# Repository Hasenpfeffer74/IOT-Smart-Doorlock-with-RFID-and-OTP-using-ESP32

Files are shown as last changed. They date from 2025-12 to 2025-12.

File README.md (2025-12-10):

# IOT Smart Doorlock with RFID & OTP using ESP32
> **Lưu ý:** Đây là dự án đại học đầu tiên của chúng em, sẽ có nhiều sai sót. Rất mong nhận được sự thông cảm và góp ý của mọi người.
## Giới thiệu (VN)
Dự án cung cấp một hệ thống khóa cửa thông minh sử dụng ESP32 với ba phương thức mở khóa: thẻ RFID, mã OTP và mã PIN. Hệ thống được thiết kế đơn giản, dễ tích hợp và phù hợp cho các ứng dụng nhà trọ, văn phòng hoặc mô hình IoT học thuật.

Hệ thống gồm các thành phần chính: ESP32, RC522 RFID, Keypad 4x4, LCD I2C, relay điều khiển khóa từ, buzzer và nguồn DC–DC. ESP32 kết nối Wi-Fi để gửi OTP qua Internet.

## Tính năng
* Mở khóa bằng thẻ RFID đã đăng ký.
* Mở khóa bằng OTP được gửi qua Telegram/email/app.
* Mở khóa bằng mã PIN cố định.
* Hiển thị trạng thái trên LCD.
* Ghi log lượt mở khóa.
* Điều khiển khóa bằng relay hoặc servo.

## Phần cứng chính
* **Vi điều khiển:** ESP32 Devkit.
* **Đầu đọc thẻ:** RFID RC522.
* **Nhập liệu:** Keypad 4×4.
* **Hiển thị:** LCD 1602 I2C.
* **Cơ cấu chấp hành:** Relay 5V điều khiển khóa điện từ 12V.
* **Thông báo:** Buzzer + LED báo trạng thái.
* **Nguồn:** Ổn áp nguồn từ 12V → 5V → 3.3V.

## Cách hoạt động
1.  Người dùng chọn phương thức: RFID, OTP hoặc PIN.
2.  ESP32 xử lý thông tin, kiểm tra tính hợp lệ.
3.  Nếu xác thực thành công, relay cấp nguồn cho khóa điện từ → cửa mở.
4.  Hệ thống tự động khóa lại sau vài giây.

---

# English Version
> **Note:** This is our first university project, so there may be errors and shortcomings. We highly appreciate your understanding and feedback.
## Introduction
This project implements a simple IoT smart doorlock system using an ESP32. It supports three authentication methods: RFID card, OTP code, and PIN input. The system is designed to be lightweight, easy to integrate, and suitable for home, office, or academic IoT demonstration projects.

It uses common hardware modules such as ESP32, RC522, keypad, LCD display, and a relay to drive a 12V solenoid lock.

## Features
* Unlock with registered RFID card.
* Unlock with OTP sent via Telegram/email/app.
* Unlock with a predefined PIN code.
* LCD display for status messages.
* Event logging for all unlock attempts.
* Relay/servo to control the lock mechanism.

## Hardware Overview
* **Controller:** ESP32 Devkit board.
* **Reader:** RC522 RFID reader.
* **Input:** 4×4 keypad.
* **Display:** LCD 1602 I2C.
* **Actuator:** 5V relay controlling 12V solenoid lock.
* **Notification:** Buzzer and indicator LED.
* **Power:** 12V → 5V/3.3V power modules.

## How It Works
1.  User chooses RFID, OTP, or PIN authentication.
2.  ESP32 verifies the credentials.
3.  If valid, relay activates and unlocks the door.
4.  The system automatically locks again after a short delay.

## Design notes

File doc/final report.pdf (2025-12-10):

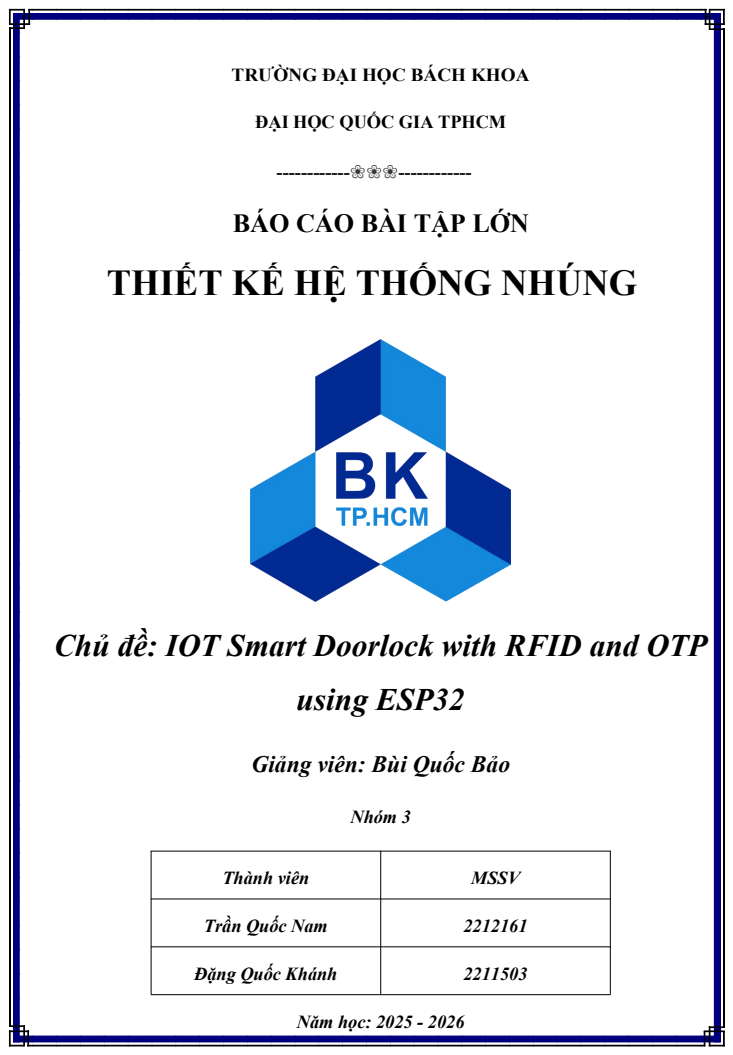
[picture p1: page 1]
using ESP32; Nhóm 3; Năm học: 2025 - 2026

TRƯỜNG ĐẠI HỌC BÁCH KHOA
ĐẠI HỌC QUỐC GIA TPHCM
------------❀❀❀------------ BÁO CÁO BÀI TẬP LỚN

THIẾT KẾ HỆ THỐNG NHÚNG

Chủ đề: IOT Smart Doorlock with RFID and OTP

Giảng viên: Bùi Quốc Bảo

Thành viên | MSSV

Trần Quốc Nam | 2212161

Đặng Quốc Khánh | 2211503

i

### MỤC LỤC

Error! The style is not specified. | 1

### CHƯƠNG 1: TỔNG QUAN

### 1.1. Vấn đề (Problem)

Các loại khóa cơ truyền thống bộc lộ nhiều hạn chế về an ninh (dễ bị cắt phá, sao chép chìa) và bất tiện khi sử dụng (quên chìa, mất chìa). Việc quản lý ra vào tại các khu vực cần bảo mật hoặc nhà trọ, văn phòng gặp nhiều khó khăn. 1.2. Ý nghĩa (Significance)

Đồ án thiết kế hệ thống khóa cửa điện tử sử dụng công nghệ thẻ từ RFID và mật khẩu số giúp nâng cao tính bảo mật, loại bỏ sự phụ thuộc vào chìa khóa cơ, đồng thời tạo tiền đề cho việc tích hợp quản lý từ xa qua Internet (IoT). 1.3. Ứng dụng (Application)

Mặc dù đây là một mô hình đồ án môn học, nhưng hệ thống khóa cửa thông minh (Smart Door Lock) được thiết kế với độ hoàn thiện cao, có tính ứng dụng thực tiễn rộng rãi trong đời sống và công nghiệp: - Hệ thống an ninh nhà ở (Smart Home): Thay thế ổ khóa cơ truyền thống tại các

căn hộ chung cư, nhà phố thông minh, giúp gia chủ không cần mang theo chùm chìa khóa cồng kềnh. - Kiểm soát ra vào văn phòng (Access Control): Ứng dụng tại các công ty, phòng

họp hoặc khu vực hạn chế (như phòng Server, kho tài liệu) để chỉ cho phép nhân viên có thẻ từ hoặc mật khẩu được cấp quyền mới được phép ra vào. - Quản lý khu nhà trọ, khách sạn (Hospitality): Giúp chủ nhà trọ quản lý người thuê

dễ dàng. Khi khách trả phòng, chỉ cần xóa mã thẻ/mật khẩu trên hệ thống mà không cần tốn chi phí thay toàn bộ ổ khóa như khóa cơ. - Tủ đồ cá nhân (Smart Locker): Ứng dụng cho hệ thống tủ gửi đồ tại siêu thị, phòng Gym, hồ bơi, tăng tính an toàn và tiện lợi cho khách hàng.

- Giáo dục và Nghiên cứu: Sản phẩm là mô hình trực quan để sinh viên nghiên cứu về lập trình hệ thống nhúng, các chuẩn giao tiếp (SPI, I2C, GPIO) và kỹ thuật điều khiển thiết bị ngoại vi trên nền tảng ESP32. 1.4. Mục tiêu (Objective)

Xây dựng hoàn thiện hệ thống khóa cửa thông minh với các chức năng: - Mở khóa bằng thẻ từ RFID. - Mở khóa bằng mật khẩu (Keypad). - Hiển thị trạng thái trên màn hình LCD. - Hệ thống hoạt động ổn định với nguồn 12V, điều khiển chốt cửa điện từ

(Solenoid Lock).

### CHƯƠNG 2: TỔNG QUAN HỆ THỐNG

### 2.1. Requirements

### 2.1.1. Functional Requirement

ID | Requirement Description
FR1 | Mở khóa bằng RFID
FR2 | Mở khóa bằng OTP (One-Time Password)
FR3 | Mở khóa bằng PIN
FR4 | Quản lý mở khóa

FR1 – Hệ thống cho phép người dùng mở khóa bằng thẻ RFID

- FR1.1. Hệ thống phải cho phép mở khóa bằng thẻ RFID hợp lệ. - FR1.2. Hệ thống phải lưu trữ và quản lý danh sách thẻ RFID được phép sử

dụng. - FR1.3. Khi quét thẻ không hợp lệ, hệ thống phải từ chối và hiển thị cảnh

báo. FR2 – Hệ thống cho phép người dùng mở khóa bằng OTP (One-Time

Password)

- FR2.1. Hệ thống phải sinh OTP ngẫu nhiên và có thời hạn sử dụng (< 60 giây). - FR2.2. OTP phải được gửi đến người dùng qua ứng dụng di

động/Telegram/email tùy cấu hình. - FR2.3. Hệ thống chỉ mở khóa khi OTP nhập vào khớp và còn hiệu lực.

FR3 – Hệ thống cho phép người dùng mở khóa bằng PIN

- FR3.1. Hệ thống phải cho phép người dùng nhập PIN cố định để mở khóa. - FR3.2. Người dùng có thể thay đổi PIN thông qua giao diện quản lý. - FR3.3. Khi nhập sai PIN nhiều lần liên tiếp, hệ thống phải khóa tạm thời và

cảnh báo. FR4 – Quản lý mở khóa

- FR4.1. Hệ thống phải điều khiển khóa điện tử (servo/relay) để mở hoặc đóng. - FR4.2. Hệ thống phải ghi lại log sự kiện. - FR4.3. Hệ thống phải cho phép reset và cập nhật firmware qua OTA (Over- The-Air). 2.1.2. Non-Functional Requirements
ID | Requirement Description
NFR1 | Thời gian phản hồi khi quét RFID, nhập OTP hoặc PIN không vượt quá 2
| giây. NFR2 Hệ thống phải hoạt động liên tục 24/7 với tỉ lệ lỗi < 1%. NFR3 Dữ liệu OTP/PIN phải được mã hóa khi truyền, và giao tiếp phải sử dụng
| HTTPS/TLS. NFR4 Hệ thống phải tiêu thụ điện năng thấp, có thể dùng pin/UPS trong trường
| hợp mất điện. NFR5 Hệ thống phải dễ mở rộng để tích hợp thêm cảm biến (camera, vân tay, cảm biến cửa…).

NFR1 – Thời gian phản hồi - NRF1.1: RFID/OTP/PIN phải được xử lý trong ≤ 2 giây. - NRF1.2: Nếu vượt ngưỡng thì hệ thống phải ghi log sự kiện lỗi. NFR2 – Độ tin cậy hệ thống

- NFR2.1: Hệ thống phải hoạt động liên tục 24/7 với uptime ≥ 99%. - NFR2.2: Có cơ chế tự khởi động lại khi treo. - NFR2.3: Khi mất mạng, RFID/PIN vẫn hoạt động offline. - NFR2.4: Tuổi thọ phần cứng tối thiểu 2 năm. NFR3 – Bảo mật dữ liệu
- NFR3.1: OTP/PIN phải được mã hóa (AES-128 trở lên). - NFR3.2: Giao tiếp sử dụng HTTPS/TLS. - NFR3.3: Không được lưu OTP dưới dạng plaintext. NFR4 – Tiêu thụ năng lượng
- NFR4.1: Có pin/UPS dự phòng ≥ 4 giờ trong trường hợp mất điện. - NFR4.2: Cảnh báo pin yếu hiển thị trên App. NFR5 – Khả năng mở rộng
- NFR5.1: Hỗ trợ tích hợp thêm cảm biến (camera, vân tay, cảm biến cửa). - NFR5.2: Cho phép giao tiếp mở rộng qua UART/I2C/SPI. - NFR5.3: Có thể quản lý cảm biến bổ sung qua App/Web. 2.1. Use Case Modelling

Hệ thống được thiết kế với 3 kịch bản sử dụng chính: Mở khóa bằng mật khẩu, Mở khóa bằng thẻ từ và Xử lý khi nhập sai (Báo động). - UC – 01: Mở khóa bằng Mật khẩu (Password Unlock)

- Mô tả: Người dùng nhập mật khẩu đã cài đặt trước thông qua bàn phím (Keypad) để mở khóa cửa. • Các bước thực hiện:

- Hệ thống ở trạng thái chờ, LCD hiển thị thông báo "Moi nhap mat khau". o Người dùng nhập các ký tự số trên Keypad 4x4. o LCD hiển thị ký tự * thay cho số thực để bảo mật. o Người dùng nhấn phím # để xác nhận. o Hệ thống kiểm tra mật khẩu. Nếu đúng:
- Buzzer kêu 1 tiếng "bíp" ngắn. o Relay đóng mạch, Solenoid rút chốt mở cửa. o LCD hiển thị "Welcome Home". o Sau 5 giây, Solenoid tự động bung chốt để khóa lại. • Yêu cầu: Hệ thống đã được cấp nguồn và mật khẩu đã được lưu trong bộ

nhớ. - UC – 02: Mở khóa bằng Thẻ RFID (RFID Unlock)

- Mô tả: Người dùng sử dụng thẻ từ hoặc móc khóa RFID đã đăng ký để chạm vào đầu đọc mở cửa nhanh chóng. • Các bước thực hiện:
- Hệ thống ở trạng thái chờ, module RFID liên tục phát sóng dò tìm thẻ. o Người dùng đưa thẻ vào phạm vi quét (2-5cm). o Đầu đọc RC522 đọc mã UID của thẻ và gửi về ESP32. o Hệ thống so sánh UID với danh sách hợp lệ. Nếu khớp:
- Buzzer kêu 1 tiếng "bíp". o Relay kích hoạt Solenoid mở cửa. o LCD hiển thị "Card Accepted". o Cửa tự động khóa lại sau 5 giây. • Yêu cầu: Thẻ RFID phải là thẻ hoạt động ở tần số 13.56MHz và đã được

nạp UID vào Code. - UC – 03: Xử lý truy cập trái phép (Access Denied)

- Mô tả: Hệ thống phản hồi khi người dùng nhập sai mật khẩu hoặc sử dụng thẻ từ không hợp lệ. • Các bước thực hiện:
- Người dùng nhập sai mật khẩu và nhấn #, hoặc quẹt thẻ chưa đăng ký. o Hệ thống kiểm tra thấy dữ liệu không trùng khớp. o Buzzer phát ra âm thanh cảnh báo (3 tiếng "bíp" dài hoặc kêu liên tục

1s). o LCD hiển thị thông báo lỗi "Wrong Password" hoặc "Invalid Card". o Relay không hoạt động, cửa vẫn ở trạng thái khóa. o Hệ thống quay lại trạng thái chờ sau 2 giây. • Yêu cầu: Hệ thống hoạt động bình thường. 2.2. System Architecture

Kiến trúc hệ thống bao gồm các khối chính là Khối nguồn, Khối hiển thị, Khối vi điều khiển, Khối di chuyển, Khối cảm biến và Khối nạp code. Trong đó: - Khối nguồn: Nguồn 12V, mạch ổn áp tạo nguồn 5V và mạch ổn áp tạo nguồn 3.3V. - Khối hiển thị: Hiển thị thông qua LCD và thông báo bằng led và buzzer. - Khối vi điều khiển: Thực hiện điều khiển các khối còn lại. - Khối chấp hành : Nhận tín hiệu kích từ vi điều khiển để cấp nguồn cho khóa. - Khối nhập liệu: Dùng để nhập dữ liệu vào. - Khối nạp code: Dùng để nạp code vào khối vi điều khiển.

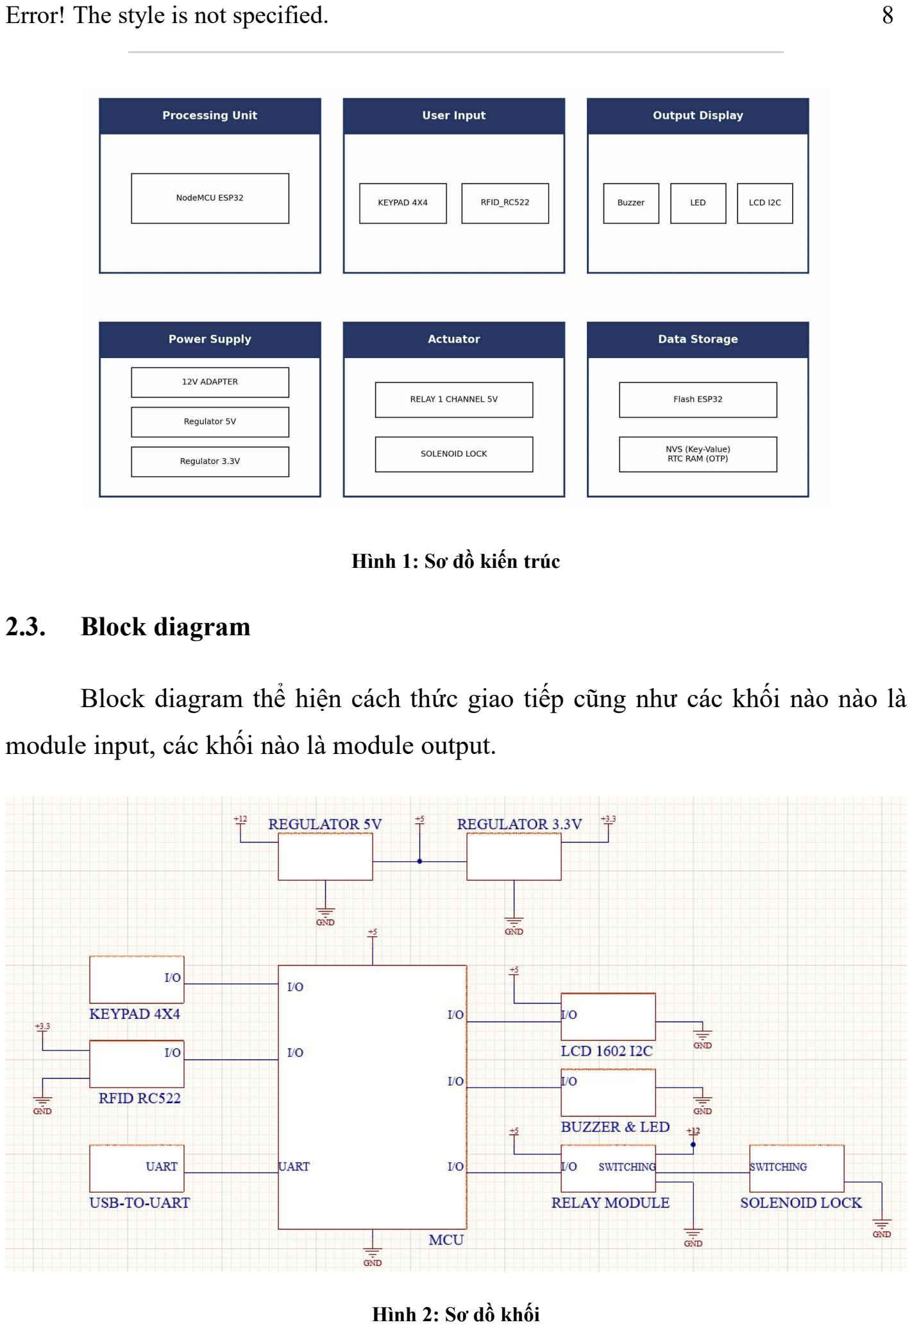
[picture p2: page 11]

Hình 1: Sơ đồ kiến trúc

### 2.3. Block diagram

Block diagram thể hiện cách thức giao tiếp cũng như các khối nào nào là module input, các khối nào là module output.

Hình 2: Sơ dồ khối

### CHƯƠNG 3 THIẾT KẾ PHẦN CỨNG

### 3.1. Khối nguồn

Hệ thống sử dụng mô hình hạ áp tầng (Cascade) để đảm bảo ổn định nhiệt và hiệu suất.- Đầu vào: 12V DC (cần thiết để Solenoid hoạt động mạnh). - Tầng 1 (12V -> 5V): Sử dụng IC L7805 để cấp nguồn cho Relay, LCD, Buzzer. Có Diode bảo vệ chống ngược cực và tụ lọc nhiễu. - Tầng 2 (5V -> 3.3V): Sử dụng IC AMS1117-3.3 để cấp nguồn cho ESP32

và module RFID (vì ESP32 và RFID hoạt động ở 3.3V, nếu cấp 5V sẽ cháy).

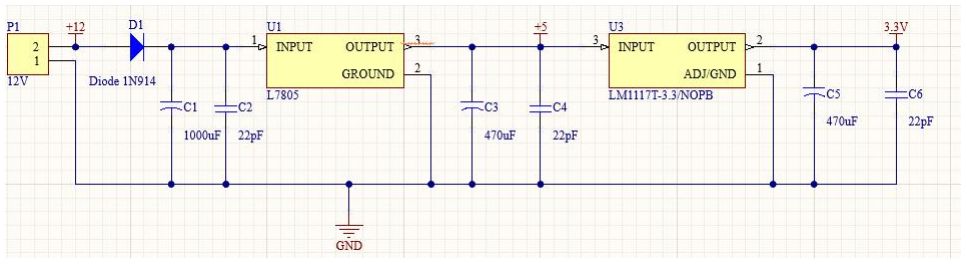
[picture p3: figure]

Hình 3: Khối nguồn

### 3.2. Khối hiển thị - LCD 1602: Sử dụng giao tiếp I2C (chân SDA, SCL) giúp tiết kiệm chân

GPIO của vi điều khiển. - Buzzer: Sử dụng Transistor NPN (C1815/2N2222) để khuếch đại dòng điện

từ chân GPIO, đảm bảo còi kêu to và bảo vệ vi điều khiển. - Led: Sử dụng LED đơn (màu Xanh) kết nối nối tiếp với điện trở hạn dòng

vào chân GPIO. Cung cấp phản hồi thị giác tức thời cho người dùng (Sáng khi mở khóa thành công, tắt hoặc nhấp nháy khi khóa/báo lỗi) hỗ trợ cho màn hình LCD và còi Buzzer.

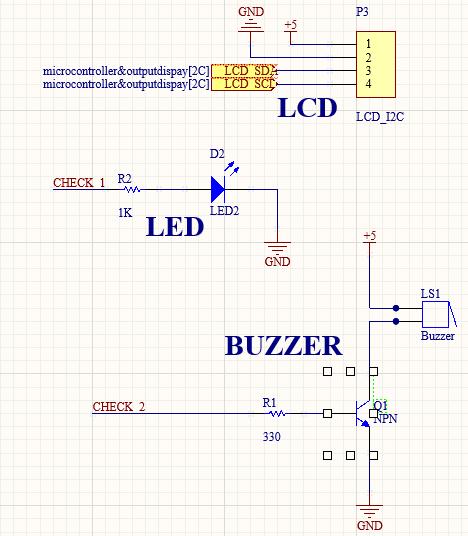
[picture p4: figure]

Hình 4: Khối hiển thị

### 3.3. Khối vi điều khiển

MCU: NodeMCU ESP32 được lựa chọn nhờ tốc độ xử lý cao (Dual-core 240MHz), bộ nhớ lớn và tích hợp sẵn Wi-Fi/Bluetooth cho các tính năng IoT mở rộng.

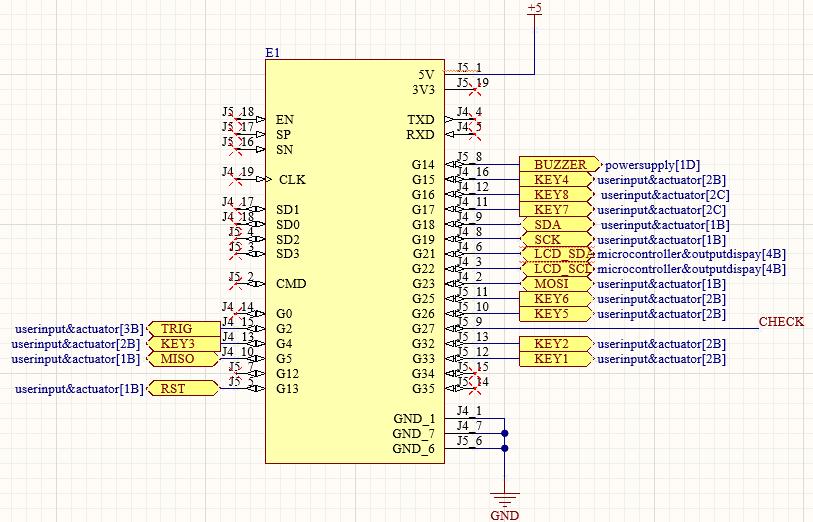
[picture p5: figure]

Hình 5: Khối vi điều khiển

### 3.4. Khối chấp hành

Đây là phần quan trọng nhất để đóng/mở cửa. - Relay 5V: Đóng vai trò cách ly giữa vi điều khiển (3.3V) và khóa từ (12V). - Solenoid Lock: Sử dụng nguồn 12V.

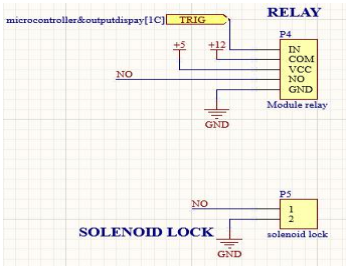
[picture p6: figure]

Hình 6: Khối chấp hành

### 3.5. Khối nhập liệu

- RFID RC522: Giao tiếp qua chuẩn SPI (MOSI, MISO, SCK, SS) cho tốc độ đọc thẻ nhanh. - Keypad 4x4: Kết nối 8 chân GPIO, sử dụng thư viện Keypad.h để quét ma

trận phím.

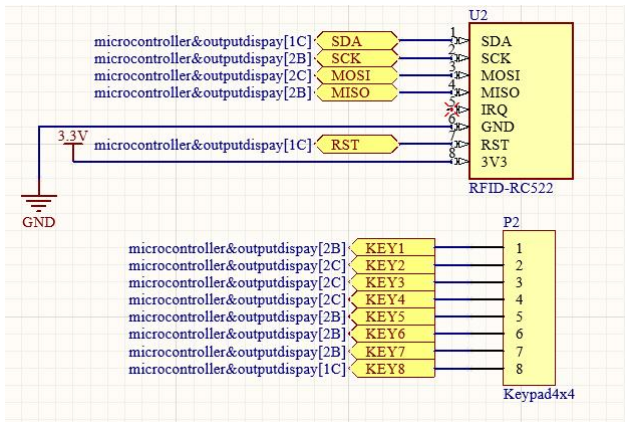
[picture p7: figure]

Hình 7: Khối nhập liệu

### CHƯƠNG 4: THIẾT KẾ PHẦN MỀM

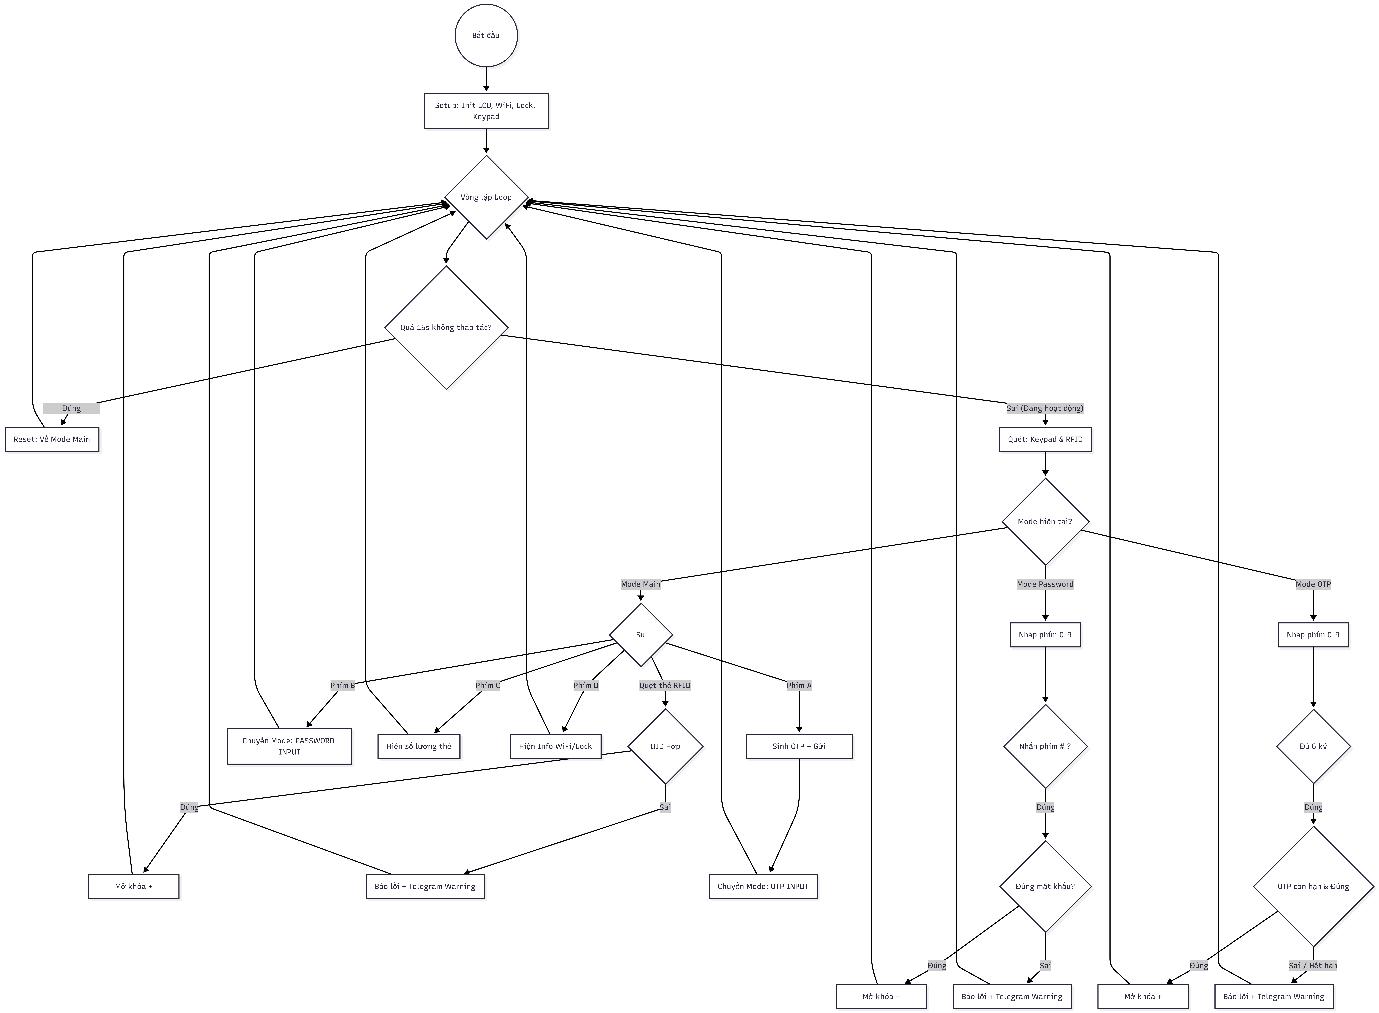
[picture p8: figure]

Hình 8: Flowchart của hệ thống

Dựa trên flowchart, hệ thống sẽ hoạt động theo luồng sau: - Trạng thái SETUP (Khởi tạo): Khi bắt đầu (Start), hệ thống thực hiện khởi tạo các

thành phần phần cứng bao gồm: màn hình LCD, kết nối WiFi, module khóa (Lock) và bàn phím (Keypad). Sau khi hoàn tất, hệ thống chuyển sang vòng lặp chính (Loop). - Trạng thái CHECK TIMEOUT (Kiểm tra thời gian chờ): Trong vòng lặp, hệ

thống liên tục kiểm tra thời gian không hoạt động. Nếu phát hiện quá 15 giây người dùng không thao tác, hệ thống thực hiện Reset: đưa giao diện về màn hình chính (Mode Main) và xóa các bộ đệm nhập liệu để bảo mật. Nếu hệ thống đang được thao tác (thời gian < 15s), hệ thống chuyển sang trạng thái quét tín hiệu đầu vào (Scan Inputs). - Trạng thái MODE MAIN (Màn hình chính): Hệ thống quét tín hiệu từ Keypad và

RFID. Tại đây xử lý các sự kiện:
- Quẹt thẻ RFID: Hệ thống kiểm tra UID. Nếu Đúng (hợp lệ), thực hiện mở khóa và gửi thông báo Telegram. Nếu Sai, báo lỗi truy cập và gửi cảnh báo Telegram. o Phím A: Hệ thống sinh mã OTP, gửi mã qua Telegram, sau đó chuyển trạng

thái sang Mode OTP. o Phím B: Hệ thống chuyển trạng thái sang Mode Password. o Phím C: LCD hiển thị số lượng thẻ RFID hợp lệ đã lưu. o Phím D: LCD hiển thị thông tin trạng thái WiFi và trạng thái Khóa. - Trạng thái MODE PASSWORD (Nhập mật khẩu): Người dùng nhập các phím số

(0-9). Khi nhấn phím #, hệ thống kiểm tra mật khẩu:
- Đúng: Thực hiện mở khóa và gửi thông báo Telegram. o Sai: Hệ thống hiển thị lỗi, báo động và gửi cảnh báo Telegram. - Trạng thái MODE OTP (Nhập mã xác thực): Người dùng nhập các phím số. Khi

bộ đệm đủ 6 ký tự, hệ thống tự động kiểm tra tính hợp lệ (mã đúng và còn thời hạn):
- Đúng & Còn hạn: Thực hiện mở khóa và gửi thông báo Telegram. o Sai hoặc Hết hạn: Hệ thống từ chối truy cập, báo lỗi tương ứng và gửi cảnh

báo Telegram.

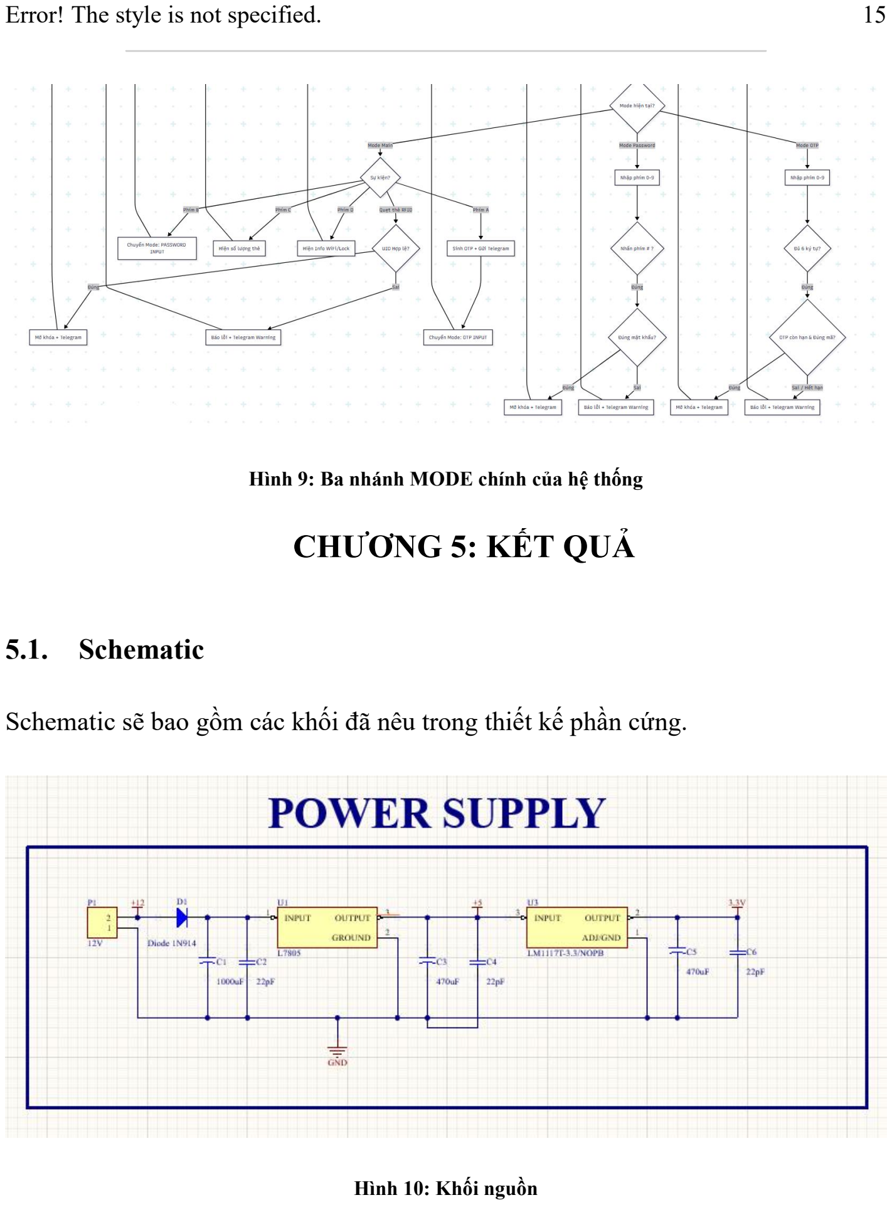
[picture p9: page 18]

Hình 9: Ba nhánh MODE chính của hệ thống

### CHƯƠNG 5: KẾT QUẢ

### 5.1. Schematic

Schematic sẽ bao gồm các khối đã nêu trong thiết kế phần cứng.

Hình 10: Khối nguồn

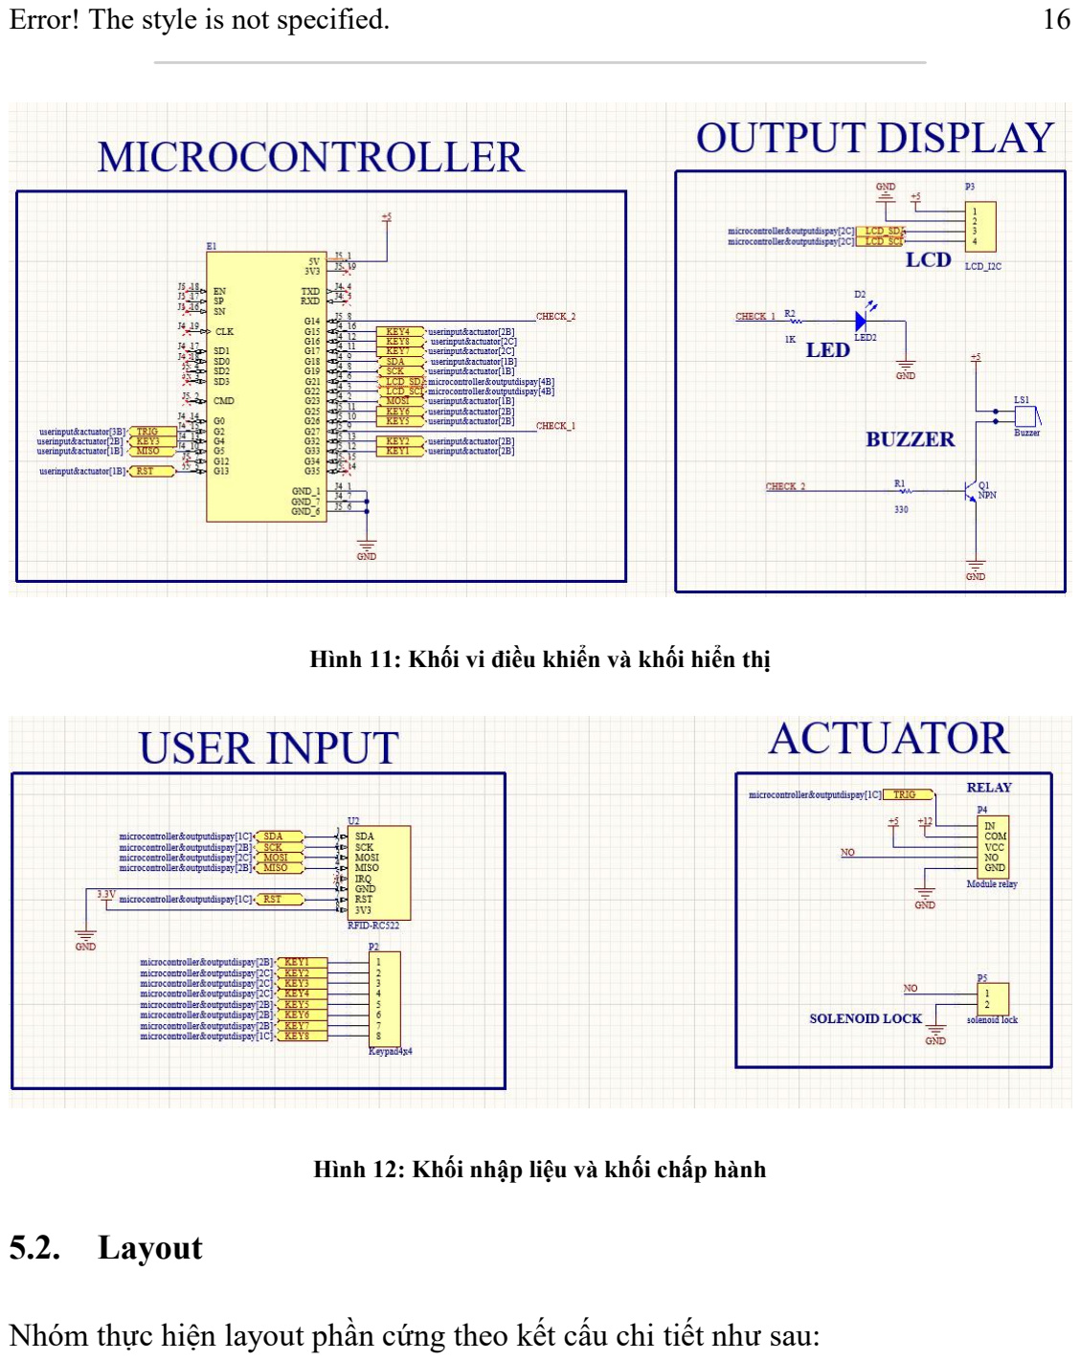
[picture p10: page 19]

Hình 11: Khối vi điều khiển và khối hiển thị

Hình 12: Khối nhập liệu và khối chấp hành

### 5.2. Layout

Nhóm thực hiện layout phần cứng theo kết cấu chi tiết như sau:

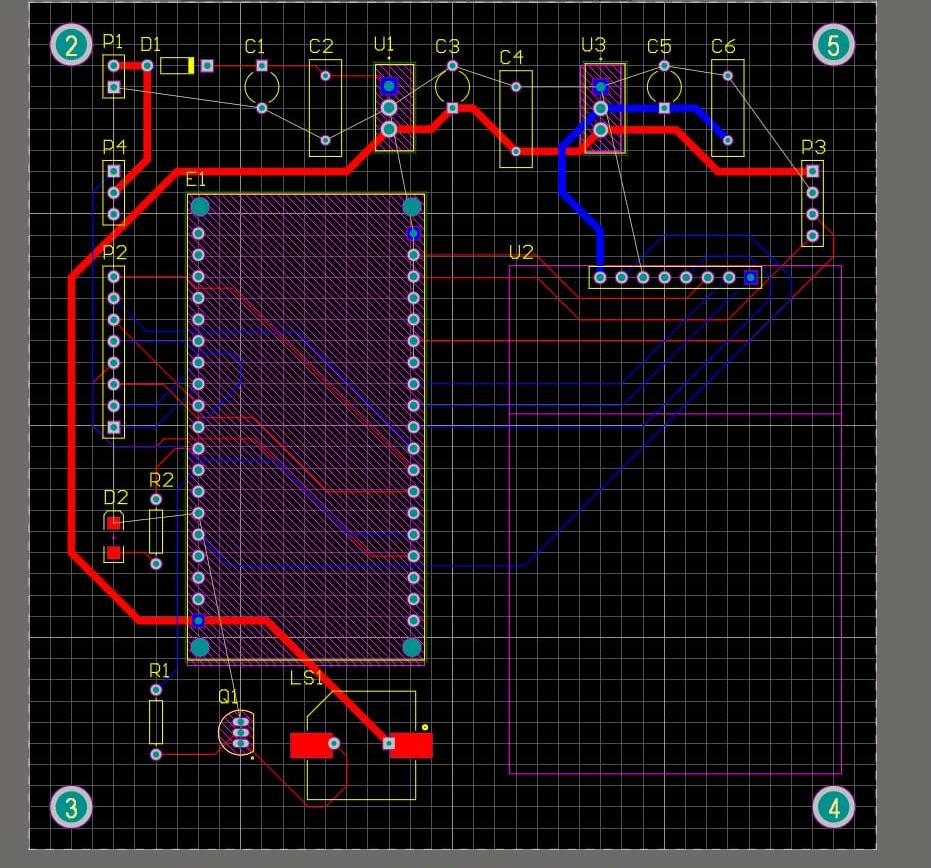
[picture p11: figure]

Hình 13: Layout của hệ thống

### 5.3. Kết quả dự án

Sau khi thiết kế và xây dựng, kết quả dự án như sau:

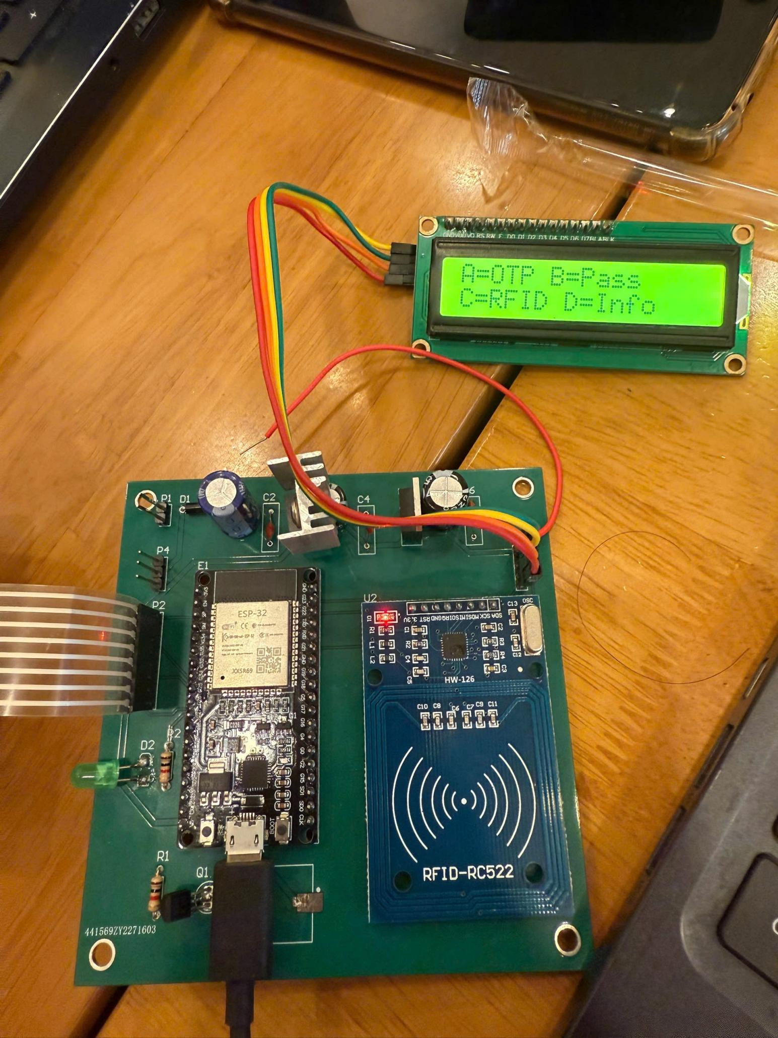
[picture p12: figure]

Hình 14: MODE của hệ thống

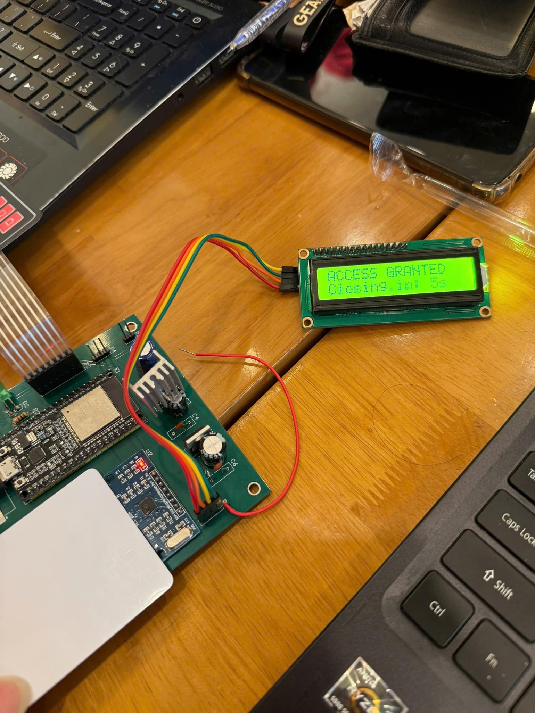
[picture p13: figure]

Hình 15: Màn hình LCD thể hiện khóa được mở trong 5s

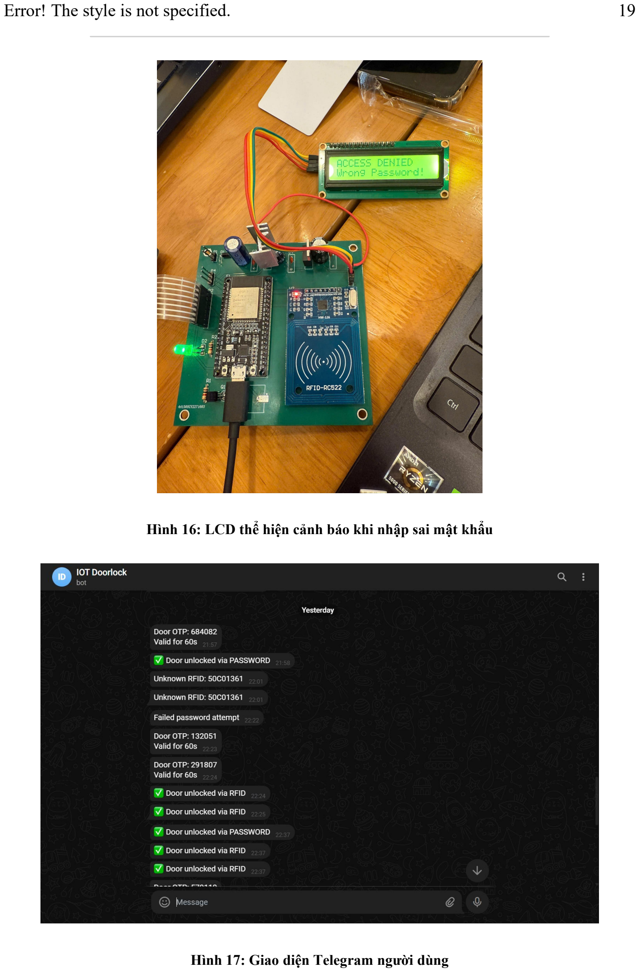
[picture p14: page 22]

Hình 16: LCD thể hiện cảnh báo khi nhập sai mật khẩu

Hình 17: Giao diện Telegram người dùng

### CHƯƠNG 6 TỔNG KẾT

Nhóm đã thiết kế và thi công thành công hệ thống khóa cửa thông minh tích hợp công nghệ IoT, hoàn thành mục tiêu xây dựng một thiết bị hoạt động ổn định trên nền tảng vi điều khiển ESP32. Hệ thống đã khắc phục được những hạn chế về an ninh và sự bất tiện của các loại khóa cơ truyền thống thông qua việc tích hợp đa dạng phương thức xác thực và khả năng quản lý từ xa qua Internet, tạo tiền đề cho các ứng dụng Smart Home hiện đại. Cụ thể, hệ thống đáp ứng tốt các yêu cầu chức năng và phi chức năng đã đề ra: - Khả năng bảo mật và vận hành đa dạng: Hệ thống thực hiện mở khóa chính

xác và nhanh chóng thông qua 3 phương thức: thẻ từ RFID, mật khẩu số (Keypad) và mã xác thực một lần (OTP), đảm bảo tính an toàn cao thay thế cho chìa khóa vật lý. - Giao diện trực quan và giám sát IoT: Trạng thái cửa được hiển thị thời gian

thực trên màn hình LCD và đồng bộ hóa thông báo về ứng dụng Telegram trên điện thoại, giúp người dùng dễ dàng theo dõi lịch sử ra vào và nhận cảnh báo truy cập trái phép tức thời. - Tính năng tự động hóa: Hệ thống hoạt động theo quy trình khép kín với cơ

chế tự động đóng chốt khóa sau 5 giây mở và tự động kích hoạt báo động (Buzzer) khi nhập sai dữ liệu nhiều lần, đảm bảo an ninh 24/7.

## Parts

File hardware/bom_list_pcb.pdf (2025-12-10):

Comment | Description | Designator | Footprint | LibRef | Quantity
Cap2 | Capacitor | C1, C3, C5 | CAPR5-4X5 | Cap2 | 3
Cap | Capacitor | C2, C4, C6 | RAD-0.3 | Cap | 3
Diode1N914 | HighConductance Fast Diode | D1 | DO-35 | Diode1N914 | 1
LED2 | Typical RED, GREEN, YELLOW, AMBERGaAs LED | D2 | 3.2X1.6X1.1 | LED2 | 1
| NodeMCUis anopen source loTplatform. ESP32is aseriesof lowcost, low powersystem-on-chip (SoC)microcontrollers with integratedWi-Fi anddual-mode Bluetooth. | E1 | MODULE_ESP32_NOD EMCU | ESP32_NODEMCU | 1
Buzzer | Magnetic Transducer Buzzer | LS1 | ABSM-1574 | Buzzer | 1
12V | Header, 2-Pin | P1 | HDR1X2 | Header 2 | 1
Keypad4x4 | Header, 8-Pin | P2 | HDR1X8 | Header 8 | 1
LCD_I2C | Header, 4-Pin | P3 | HDR1X4 | Header 4 | 1
Header 3 | Header, 3-Pin | P4 | HDR1X3 | Header 3 | 1
NPN | NPNBipolar Transistor | Q1 | TO-226-AA | NPN | 1
Res1 | Resistor | R1, R2 | AXIAL-0.3 | Res1 | 2
L7805 | StandardRegulator Pos5V1.5A3-Pin(3+Tab)TO-220FP Tube | U1 | TO255P1020X450X20 00-3 | L7805 | 1
RFID-RC522 | Development kit inan integrated reader/writer IC MFRC522for contactless communicationat 13.56MHz. | U2 | RFID-RC522 | RFID-RC522 | 1
LM1117T-3.3/NOPB | 800-mA15-Vlinear voltageregulator | U3 | TO254P1054X470X19 55-3 | LM1117T-3.3/NOPB | 1

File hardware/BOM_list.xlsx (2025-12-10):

STT | Tên linh kiện | Số lượng | Đơn giá | Link
1 | Kit phát triển Wifi BLE SoC ESP32 S3 WeAct ESP32-S3-B N16R8 | 1 | 190000 | https://hshop.vn/kit-rf-thu-phat-wifi-ble-esp32-nodemcu-32s-ch340-ai-thinker
2 | Bàn phím ma trận mềm 4x4 keypad | 1 | 12000 | https://hshop.vn/ban-phim-ma-tran-mem-4x4
3 | Solenoid Lock | 1 | 27000 | https://hshop.vn/dong-co-rc-servo-9g-360
4 | Mạch RFID NFC 13.56MHz RC522 | 1 | 28000 | https://hshop.vn/mach-rfid-rc522-nfc-13-56mhz
5 | Mạch còi buzzer | 1 | 10000 | https://hshop.vn/mach-buzzer-5v
6 | Mạch hiển thị MKE-M07 LCD1602 I2C module | 1 | 95000 | https://hshop.vn/mach-hien-thi-mkl-m07-lcd1602-i2c-module
7 | LM7805 Mạch Ổn Áp 5V 1.2A | 1 | 7000 | https://www.thegioiic.com/lm7805-mach-on-ap-5v-1-2a
8 | LD1117V33 IC Ổn Áp 3.3V 800mA | 1 | 6000 | https://www.thegioiic.com/ld1117v33-ic-on-ap-3-3v-800ma
9 | Module Relay 1 Kênh 5V-220VAC10A | 1 | 30000 | https://dientu360.com/module-relay-1-kenh-5v-220vac10a-cach-ly-quang
10 | Pin Sạc 18650 Li-Ion Rechargeable Battery 3.7V 2500mAh 10C | 3 | 120000 | https://hshop.vn/pin-sac-18650-li-ion-rechargeable-battery-3-7v-2500mah-10c
111 | Tụ 470uF, 22pF, trở 1K
 |  |  | 525000

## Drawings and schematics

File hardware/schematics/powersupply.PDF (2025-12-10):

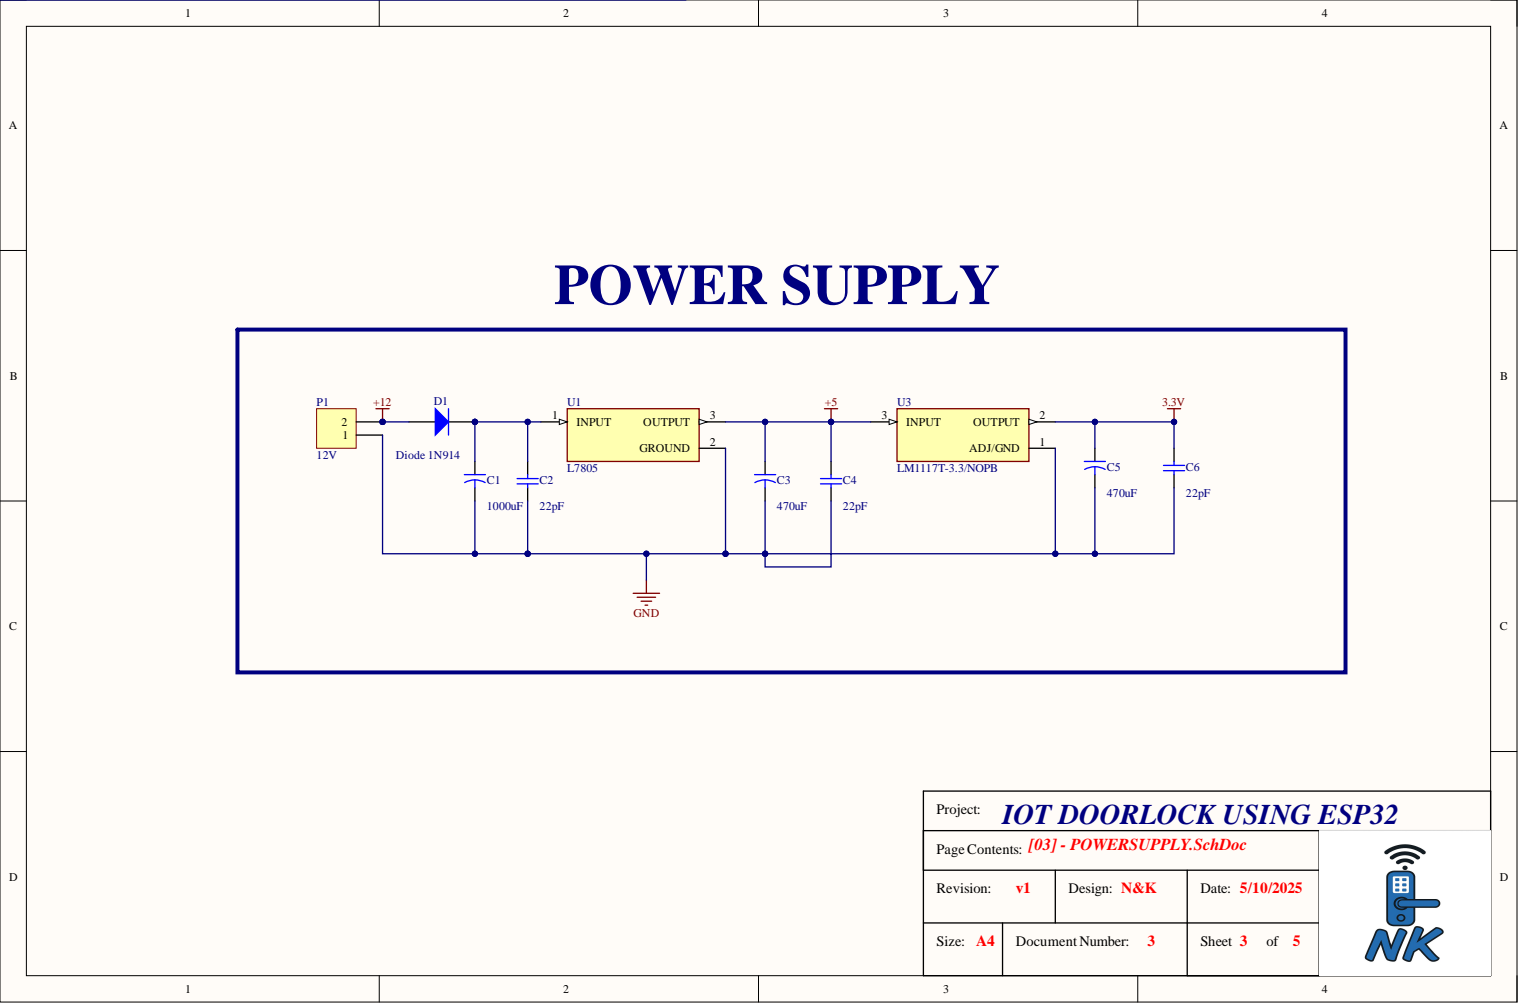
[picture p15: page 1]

[03] - POWERSUPPL Y.SchDoc P a g eCo nte n t s :

v 1 Re visi o n : | N&K Desi g n : | 5/1 0/2 0 2 5 Da te :

Siz e : A4 | Do c ume nt Nu mb e r : 3 | S h e e t 3 o f 5

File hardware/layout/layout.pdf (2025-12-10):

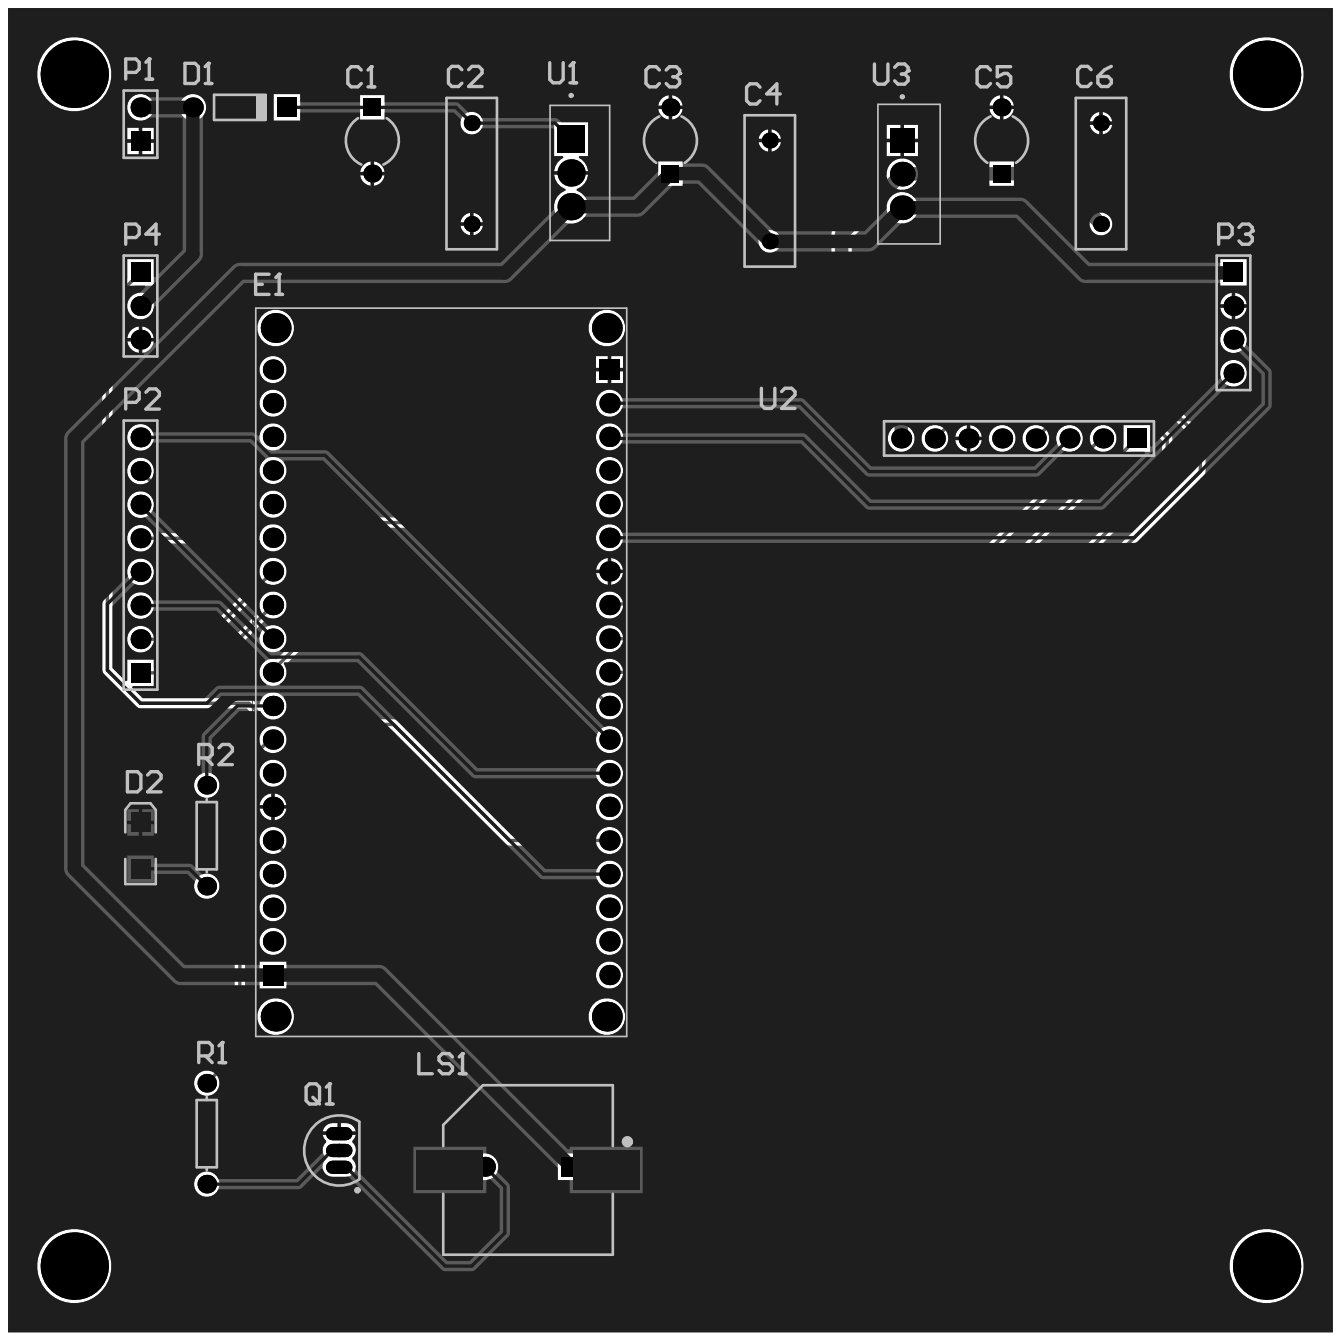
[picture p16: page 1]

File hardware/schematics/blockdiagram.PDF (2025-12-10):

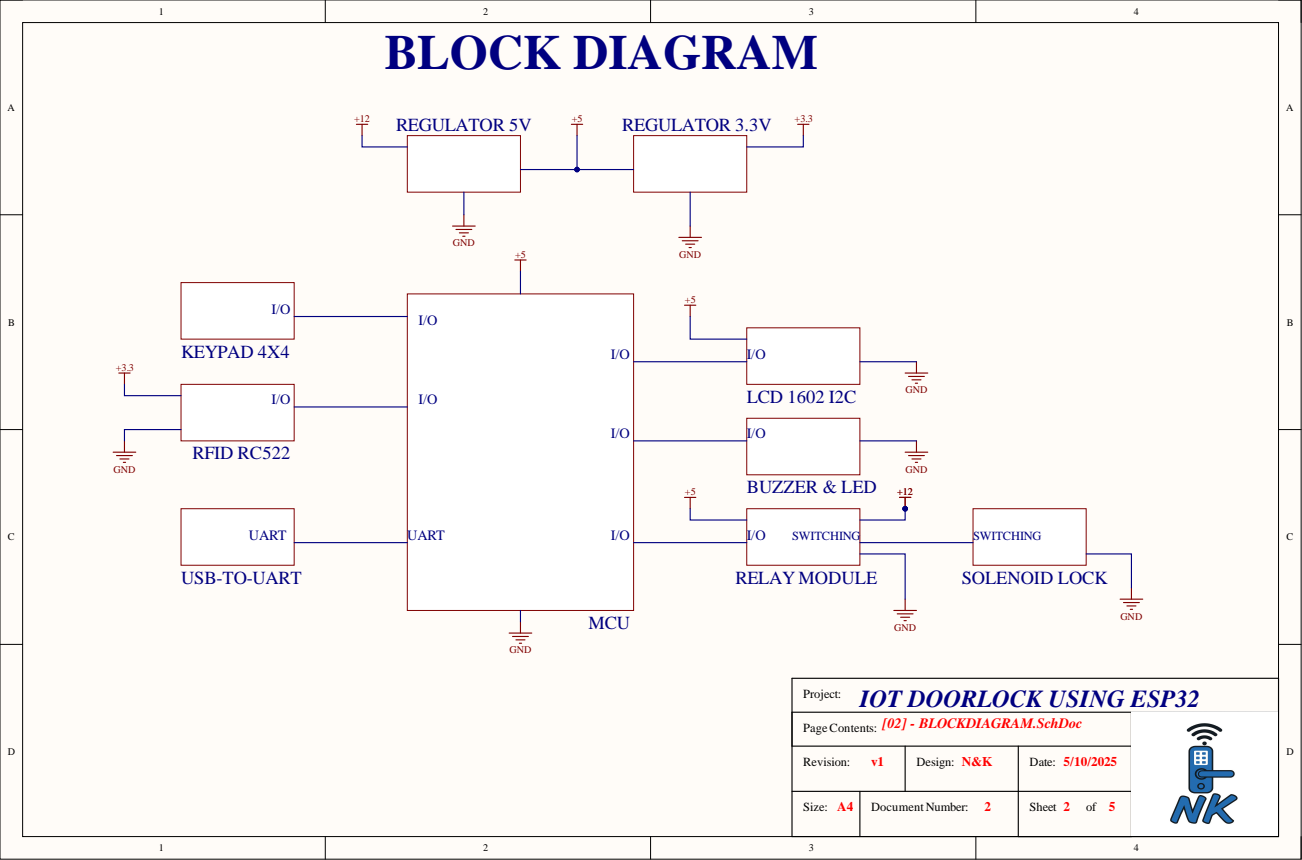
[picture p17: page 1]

[02] - BLOCKDIAGRAM.SchDoc PageContents:

v1 Revision: | N&K Design: | 5/10/2025 Date:

Size: A4 | Document Number: 2 | Sheet 2 of 5

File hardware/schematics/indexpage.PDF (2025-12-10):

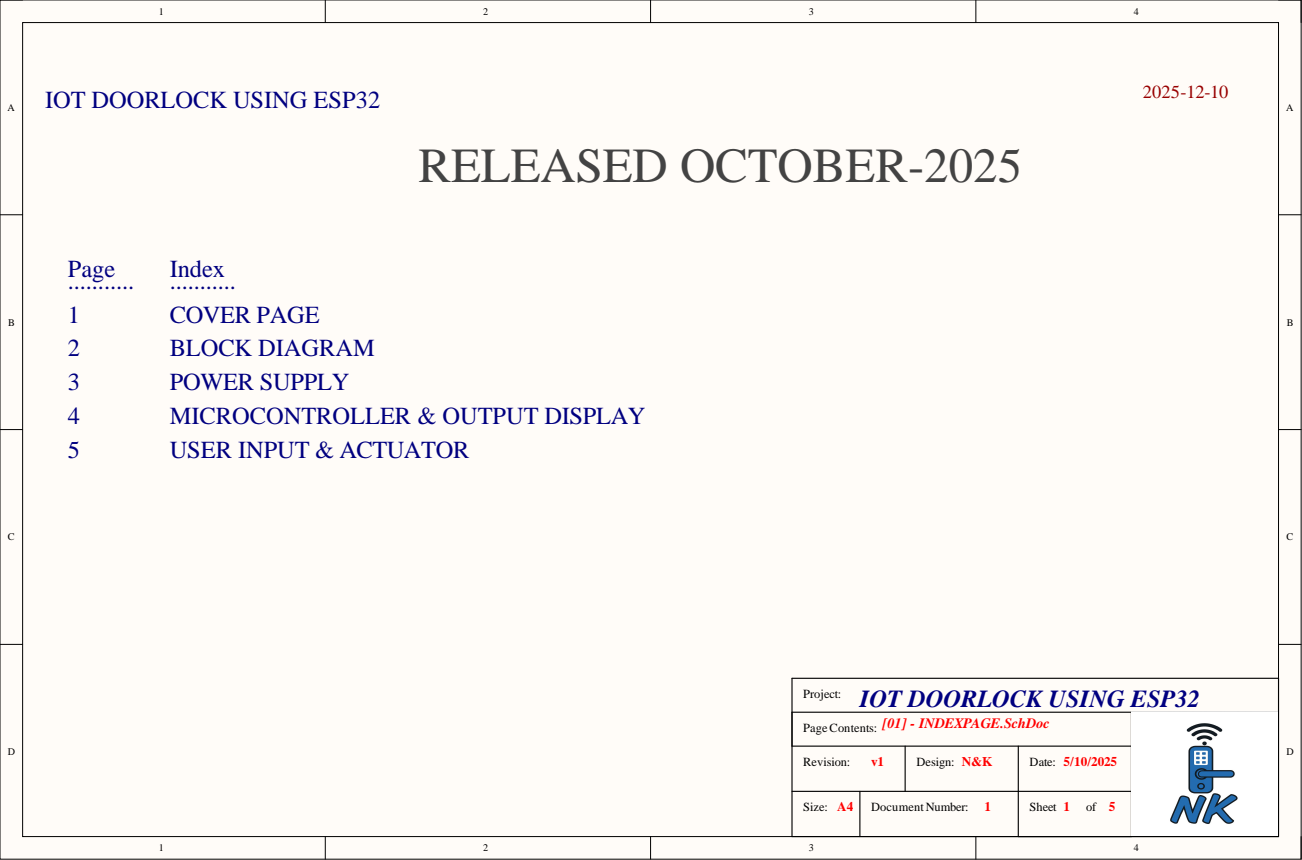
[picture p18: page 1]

[01] - INDEXPAGE.SchDoc PageContents:

v1 Revision: | N&K Design: | 5/10/2025 Date:

Size: A4 | Document Number: 1 | Sheet 1 of 5


[02] - BLOCKDIAGRAM.SchDoc PageContents:

v1 Revision: | N&K Design: | 5/10/2025 Date:

Size: A4 | Document Number: 2 | Sheet 2 of 5


[03] - POWERSUPPL Y.SchDoc P a g eCo nte n t s :

v 1 Re visi o n : | N&K Desi g n : | 5/1 0/2 0 2 5 Da te :

Siz e : A4 | Do c ume nt Nu mb r 3 | S h t 3 o f 5

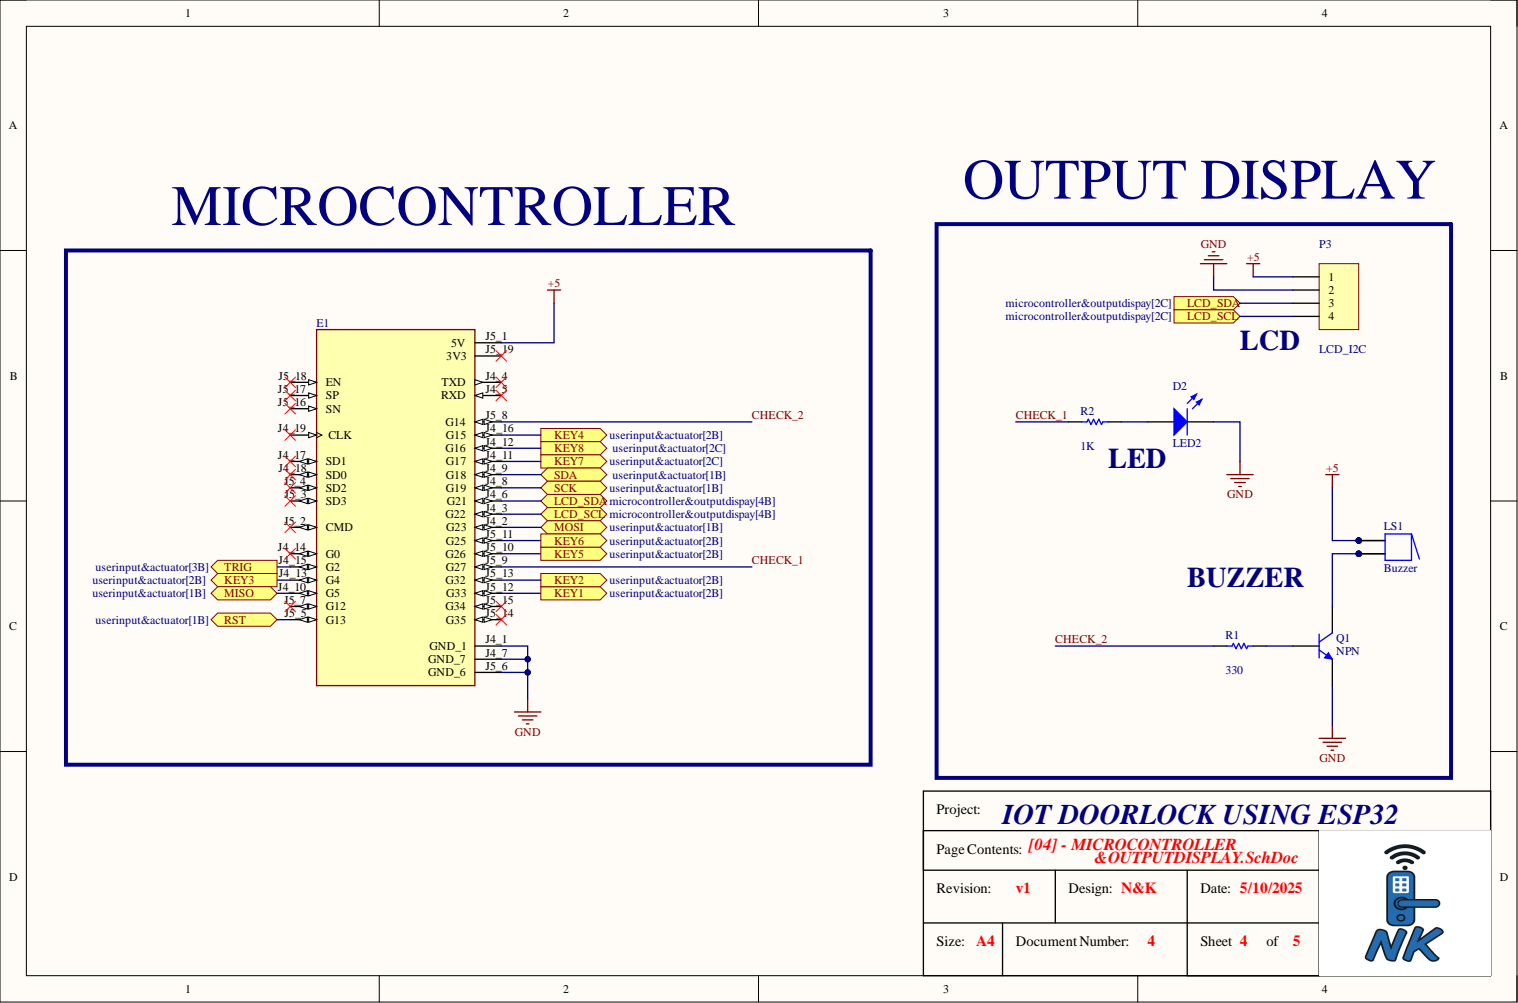
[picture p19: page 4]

J 4 _ | 7
J 5 _ | 6

[04] - MICROCONTROLLER P a g eCo nte n t s : & O UTPUTDISPLA Y.SchDoc

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

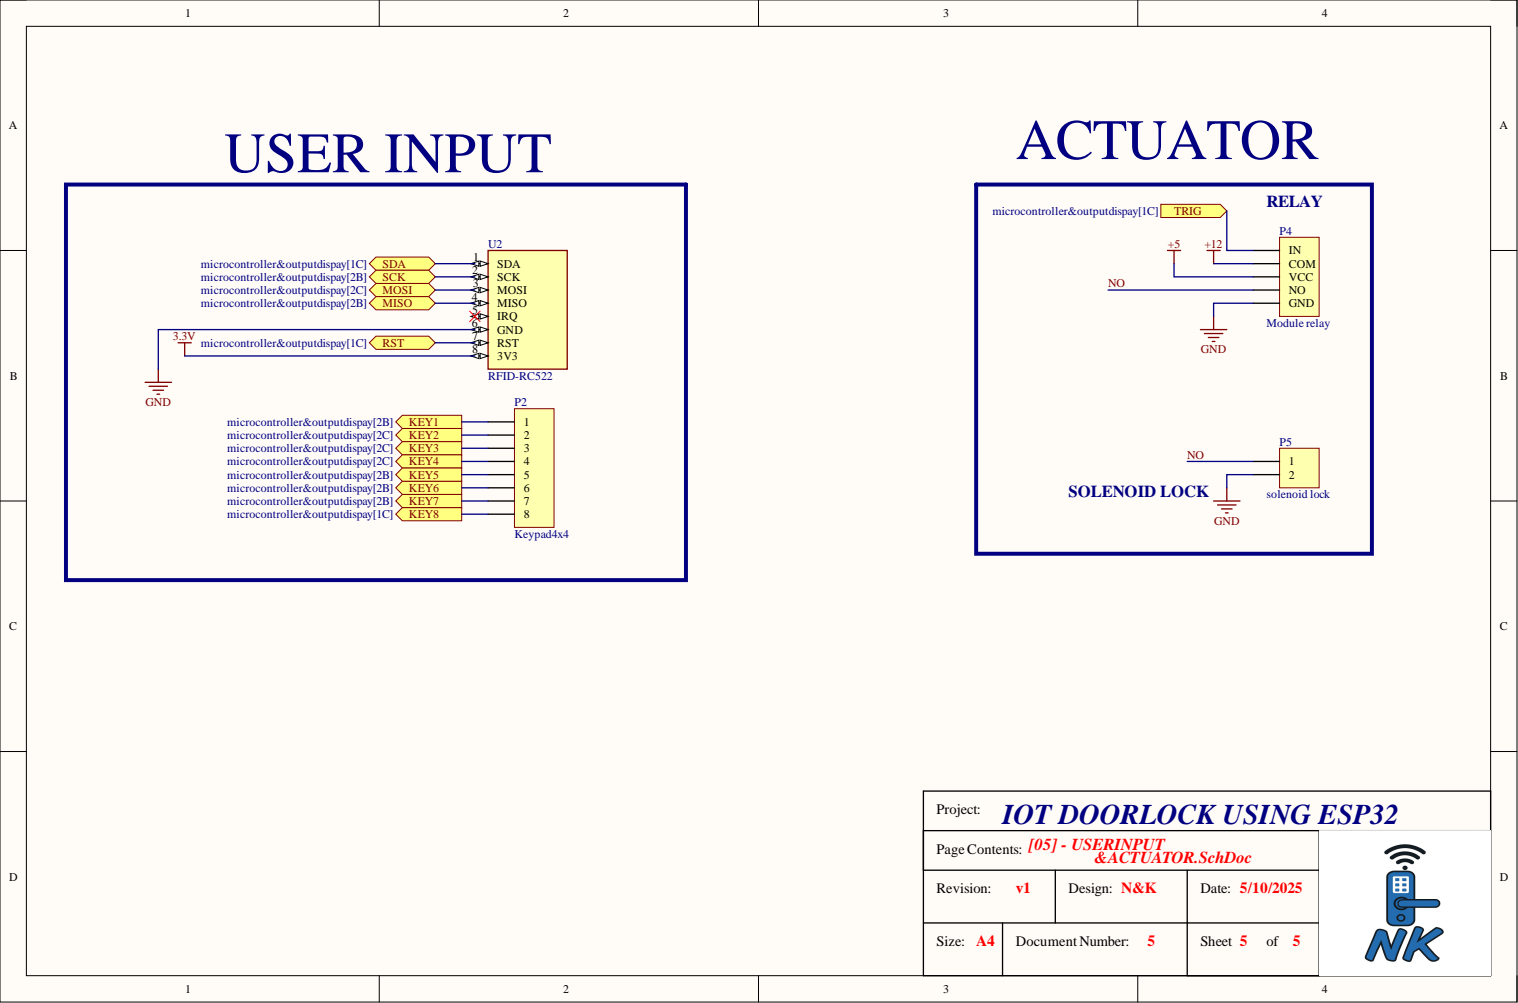
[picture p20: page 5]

[05] -USERINPU T P a g eCo nte n t s : &ACTUA TOR.SchDoc

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

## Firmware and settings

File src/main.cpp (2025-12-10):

// ═══════════════════════════════════════════════════════════
// FILE: src/main.cpp
// ═══════════════════════════════════════════════════════════
/**
 * @file main.cpp
 * @brief Smart Doorlock Main Application
 * @author Nhom3
 * @version 2.0.0
 * @date 2025
 * 
 * @description
 * IoT Smart Doorlock with multiple authentication methods:
 * - RFID Card Authentication
 * - OTP (One-Time Password) via Telegram
 * - PIN Password Authentication
 */

#include <Arduino.h>
#include "Config.h"

// BSP Layer
#include "BSP/BSP_GPIO.h"
#include "BSP/BSP_SPI.h"
#include "BSP/BSP_I2C.h"

// Driver Layer
#include "Drivers/RFID/RFID_Driver.h"
#include "Drivers/LCD/LCD_Driver.h"
#include "Drivers/Keypad/Keypad_Driver.h"
#include "Drivers/Lock/Lock_Driver.h"
#include "Drivers/Buzzer/Buzzer_Driver.h"
#include "Drivers/LED/LED_Driver.h"

// Application Layer
#include "App/WiFiManager/WiFiManager.h"
#include "App/TelegramNotifier/TelegramNotifier.h"
#include "App/OTPManager/OTPManager.h"
#include "App/PasswordManager/PasswordManager.h"
#include "App/MenuManager/MenuManager.h"
#include "App/DoorlockController/DoorlockController.h"

// ═══════════════════════════════════════════════════════════
// GLOBAL OBJECTS
// ═══════════════════════════════════════════════════════════

// Driver Layer Instances
RFID_Driver rfid(RFID_SS_PIN, RFID_RST_PIN);
LCD_Driver lcd(LCD_ADDRESS, LCD_COLS, LCD_ROWS);
Keypad_Driver keypad;
Lock_Driver lock(LOCK_PIN, RELAY_ACTIVE_LOW, SOLENOID_REVERSE);
Buzzer_Driver buzzer(BUZZER_PIN);
LED_Driver led(LED_PIN);

// Application Layer Instances
WiFiManager wifi(WIFI_SSID, WIFI_PASSWORD);
TelegramNotifier telegram(BOT_TOKEN, CHAT_ID, &wifi);
OTPManager otpManager(&telegram, &lcd);
PasswordManager passwordManager(DOOR_PASSWORD, &lcd, PASSWORD_LENGTH);
MenuManager menu(&lcd, &rfid);
DoorlockController doorlock(&lock, &led, &buzzer, &lcd, &telegram);

// ═══════════════════════════════════════════════════════════
// SYSTEM STATE
// ═══════════════════════════════════════════════════════════

enum SystemMode {
    MODE_MAIN,          // Main menu - waiting for input
    MODE_PASSWORD,      // Password entry mode
    MODE_OTP           // OTP entry mode
};

SystemMode currentMode = MODE_MAIN;
unsigned long lastActivity = 0;

// ═══════════════════════════════════════════════════════════
// FUNCTION DECLARATIONS
// ═══════════════════════════════════════════════════════════

void printStartupBanner();
void initializeSystem();
void checkTimeout();
void handleKeyInput(char key);
void handleMainMenuInput(char key);
void handlePasswordInput(char key);
void handleOTPInput(char key);
void handleRFID();

// ═══════════════════════════════════════════════════════════
// SETUP FUNCTION
// ═══════════════════════════════════════════════════════════

void setup() {
    // Initialize Serial Communication
    Serial.begin(SERIAL_BAUD);
    delay(500);
    
    // Print startup banner
    printStartupBanner();
    
    // Initialize all system components
    initializeSystem();
    
    // Show welcome screen
    menu.showWelcome();
    
    // Show main menu
    menu.showMainMenu();
    
    // System ready
    Serial.println("");
    Serial.println("========================================");
    Serial.println("SYSTEM READY - WAITING FOR INPUT");
    Serial.println("========================================");
    Serial.println("");
    
    // Initial feedback
    led.blink(2, 150);
    buzzer.beep(100);
    
    // Reset activity timer
    lastActivity = millis();
}

// ═══════════════════════════════════════════════════════════
// MAIN LOOP
// ═══════════════════════════════════════════════════════════

void loop() {
    // Maintain WiFi connection
    wifi.maintain();
    
    // Check for timeout (return to main menu after inactivity)
    checkTimeout();
    
    // Handle keypad input
    char key = keypad.getKey();
    if (key) {
        lastActivity = millis();
        handleKeyInput(key);
    }
    
    // Handle RFID scanning (only in main mode)
    if (currentMode == MODE_MAIN) {
        handleRFID();
    }
    
    // Small delay to prevent CPU hogging
    delay(10);
}

// ═══════════════════════════════════════════════════════════
// INITIALIZATION FUNCTIONS
// ═══════════════════════════════════════════════════════════

void printStartupBanner() {
    Serial.println("");
    Serial.println("");
    Serial.println("========================================");
    Serial.println("                                        ");
    Serial.println("   SMART DOORLOCK SYSTEM v2.0           ");
    Serial.println("                                        ");
    Serial.println("   Multi-Authentication System          ");
    Serial.println("   IoT Telegram Integration             ");
    Serial.println("                                        ");
    Serial.println("========================================");
    Serial.println("   Author:  Nhom3");
    Serial.print("   Build:   ");
    Serial.print(__DATE__);
    Serial.print(" ");
    Serial.println(__TIME__);
    Serial.print("   Version: ");
    Serial.println(FIRMWARE_VERSION);
    Serial.println("========================================");
    Serial.println("");
}

void initializeSystem() {
    Serial.println("Starting System Initialization...");
    Serial.println("");
    
    // Initialize BSP Layer
    Serial.println("----------------------------------------");
    Serial.println("STEP 1: BSP Layer Initialization");
    Serial.println("----------------------------------------");
    
    BSP_GPIO::init();
    BSP_SPI::init();
    BSP_I2C::init();
    
    Serial.println("");
    
    // Initialize Driver Layer
    Serial.println("----------------------------------------");
    Serial.println("STEP 2: Driver Layer Initialization");
    Serial.println("----------------------------------------");
    
    rfid.init();
    lcd.init();
    keypad.init();
    lock.init();
    buzzer.init();
    led.init();
    
    Serial.println("");
    
    // Initialize Application Layer
    Serial.println("----------------------------------------");
    Serial.println("STEP 3: App Layer Initialization");
    Serial.println("----------------------------------------");
    
    wifi.init();
    telegram.init();
    otpManager.init();
    passwordManager.init();
    menu.init();
    doorlock.init();
    
    Serial.println("");
    Serial.println("All layers initialized successfully!");
    Serial.println("");
}

// ═══════════════════════════════════════════════════════════
// INPUT HANDLING FUNCTIONS
// ═══════════════════════════════════════════════════════════

void handleKeyInput(char key) {
    Serial.print("Key pressed: [");
    Serial.print(key);
    Serial.println("]");
    
    switch (currentMode) {
        case MODE_MAIN:
            handleMainMenuInput(key);
            break;
            
        case MODE_PASSWORD:
            handlePasswordInput(key);
            break;
            
        case MODE_OTP:
            handleOTPInput(key);
            break;
    }
}

void handleMainMenuInput(char key) {
    buzzer.beep(50);
    
    switch (key) {
        case 'A':
            Serial.println("Mode: OTP Authentication");
            if (otpManager.generateOTP()) {
                currentMode = MODE_OTP;
                otpManager.showInputScreen();
            } else {
                lcd.showMessageTimed("OTP Failed", "Check WiFi", 2000);
                menu.showMainMenu();
            }
            break;
            
        case 'B':
            Serial.println("Mode: Password Authentication");
            currentMode = MODE_PASSWORD;
            passwordManager.showInputScreen();
            break;
            
        case 'C':
            Serial.println("Showing RFID Info");
            menu.showRFIDInfo();
            break;
            
        case 'D':
            Serial.println("Showing System Info");
            menu.showSystemInfo(wifi.isConnected(), doorlock.isLocked());
            break;
            
        default:
            break;
    }
}

void handlePasswordInput(char key) {
    buzzer.beep(30);
    
    if (key == '#') {
        Serial.println("Verifying password...");
        if (passwordManager.verify()) {
            Serial.println("Password correct!");
            doorlock.unlockDoor("PASSWORD");
        } else {
            Serial.println("Password incorrect!");
            doorlock.showAccessDenied("Wrong Password");
            telegram.sendAccessDeniedAlert("Failed password attempt");
        }
        
        currentMode = MODE_MAIN;
        passwordManager.reset();
        menu.showMainMenu();
    }
    else if (key == '*') {
        Serial.println("Clearing password input");
        passwordManager.showInputScreen();
    }
    else if (key == 'D') {
        Serial.println("Password input cancelled");
        currentMode = MODE_MAIN;
        passwordManager.reset();
        menu.showMainMenu();
    }
    else if (key >= '0' && key <= '9') {
        passwordManager.addDigit(key);
    }
}

void handleOTPInput(char key) {
    buzzer.beep(30);
    
    if (key == '*') {
        Serial.println("Clearing OTP input");
        otpManager.showInputScreen();
    }
    else if (key == 'D') {
        Serial.println("OTP input cancelled");
        currentMode = MODE_MAIN;
        otpManager.reset();
        menu.showMainMenu();
    }
    else if (key >= '0' && key <= '9') {
        bool full = otpManager.addDigit(key);
        
        if (full) {
            Serial.println("Verifying OTP...");
            delay(300);
            
            int otp = otpManager.getInputBuffer().toInt();
            int result = otpManager.verify(otp);
            
            if (result == 1) {
                Serial.println("OTP valid!");
                doorlock.unlockDoor("OTP");
            } 
            else if (result == -3) {
                Serial.println("OTP expired!");
                doorlock.showAccessDenied("OTP Expired");
            } 
            else {
                Serial.println("OTP invalid!");
                doorlock.showAccessDenied("Wrong OTP");
            }
            
            currentMode = MODE_MAIN;
            menu.showMainMenu();
        }
    }
}

void handleRFID() {
    String uid = rfid.readCard();
    
    if (uid != "") {
        Serial.print("RFID Card detected: ");
        Serial.println(uid);
        
        if (rfid.isCardValid(uid)) {
            Serial.println("Valid RFID card!");
            doorlock.unlockDoor("RFID");
        } else {
            Serial.println("Invalid RFID card!");
            doorlock.showAccessDenied("Invalid Card");
            telegram.sendMessage("Unknown RFID card: " + uid);
        }
        
        menu.showMainMenu();
        lastActivity = millis();
    }
}

// ═══════════════════════════════════════════════════════════
// TIMEOUT HANDLING
// ═══════════════════════════════════════════════════════════

void checkTimeout() {
    if (currentMode != MODE_MAIN) {
        unsigned long now = millis();
        
        if (now - lastActivity > SCREEN_TIMEOUT) {
            Serial.println("");
            Serial.println("TIMEOUT: Returning to main menu");
            Serial.println("");
            
            currentMode = MODE_MAIN;
            passwordManager.reset();
            otpManager.reset();
            
            menu.showMainMenu();
            
            buzzer.beepWarning();
            led.blink(2, 100);
            
            lastActivity = millis();
        }
    }
}

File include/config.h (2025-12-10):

// ═══════════════════════════════════════════════════════════
// FILE: include/Config.h
// ═══════════════════════════════════════════════════════════
#ifndef CONFIG_H
#define CONFIG_H

#include <Arduino.h>

// ═══════════════════════════════════════════════════════════
// HARDWARE PIN CONFIGURATION
// ═══════════════════════════════════════════════════════════

// ─────────────────────────────────────────────────────────
// SPI Pins (RFID RC522)
// ─────────────────────────────────────────────────────────
#define RFID_SS_PIN     18      // SDA/SS
#define RFID_RST_PIN    13      // RST
#define RFID_SCK_PIN    19      // SCK
#define RFID_MISO_PIN   5       // MISO
#define RFID_MOSI_PIN   23      // MOSI

// ─────────────────────────────────────────────────────────
// I2C Pins (LCD 1602)
// ─────────────────────────────────────────────────────────
#define I2C_SDA_PIN     21      // SDA (ESP32 default)
#define I2C_SCL_PIN     22      // SCL (ESP32 default)
#define I2C_FREQUENCY   100000  // 100kHz

// ─────────────────────────────────────────────────────────
// GPIO Output Pins
// ─────────────────────────────────────────────────────────
#define LOCK_PIN        2       // Relay for Solenoid Lock
#define LED_PIN         14      // Status LED
#define BUZZER_PIN      27      // 5V Active Buzzer

// ─────────────────────────────────────────────────────────
// Keypad Matrix Pins (4x4)
// ─────────────────────────────────────────────────────────
#define KEYPAD_ROWS     4
#define KEYPAD_COLS     4

// Row pins (connect to keypad rows)
#define KEYPAD_ROW_1    33
#define KEYPAD_ROW_2    32
#define KEYPAD_ROW_3    4
#define KEYPAD_ROW_4    15

// Column pins (connect to keypad columns)
#define KEYPAD_COL_1    26
#define KEYPAD_COL_2    25
#define KEYPAD_COL_3    17
#define KEYPAD_COL_4    16

// ═══════════════════════════════════════════════════════════
// NETWORK CONFIGURATION
// ═══════════════════════════════════════════════════════════
#define WIFI_SSID       "YOUR WIFI SSID"    //Enter your WIFI name
#define WIFI_PASSWORD   "YOUR WIFI PASSWORD"  //Enter your WIFI password
#define WIFI_TIMEOUT    10000   // 10 seconds

/* ═══════════════════════════════════════════════════════════
 * TELEGRAM BOT CREDENTIALS
 * 
 * How to get Bot Token:
 * 1. Open Telegram, search @BotFather
 * 2. Send /newbot
 * 3. Follow instructions
 * 4. Copy the token
 * 
 * How to get Chat ID:
 * 1. Open Telegram, search @userinfobot
 * 2. Send /start
 * 3. Copy your ID number
 * ═══════════════════════════════════════════════════════════ */
#define BOT_TOKEN       "8311757423:AAFPZOz62SOHCWVKgkjBy4yBoguouTvL3Qg"
#define CHAT_ID         "1602072119"

// ═══════════════════════════════════════════════════════════
// SECURITY CONFIGURATION
// ═══════════════════════════════════════════════════════════

// ─────────────────────────────────────────────────────────
// Password Settings
// ─────────────────────────────────────────────────────────
#define DOOR_PASSWORD   "1234"
#define PASSWORD_LENGTH 4

// ─────────────────────────────────────────────────────────
// OTP Settings
// ─────────────────────────────────────────────────────────
#define OTP_LENGTH      6
#define OTP_EXPIRE_TIME 60000   // 60 seconds

/* ═══════════════════════════════════════════════════════════
 * RFID CARD UIDS
 * 
 * How to get UID:
 * 1. Upload RFID test sketch
 * 2. Scan your card
 * 3. Check Serial Monitor for UID
 * 4. Add UID to array below (format: "FA904A06")
 * ═══════════════════════════════════════════════════════════ */
const String VALID_RFID_UIDS[] = {
    "FA904A06"
    // Add more card UIDs here
    // "12345678",
    // "ABCDEF01"
};
const int VALID_RFID_COUNT = sizeof(VALID_RFID_UIDS) / sizeof(VALID_RFID_UIDS[0]);

// ═══════════════════════════════════════════════════════════
// LCD CONFIGURATION
// ═══════════════════════════════════════════════════════════
#define LCD_ADDRESS     0x27    // I2C address (try 0x3F if 0x27 doesn't work)
#define LCD_COLS        16
#define LCD_ROWS        2

// ═══════════════════════════════════════════════════════════
// LOCK CONTROL CONFIGURATION
// ═══════════════════════════════════════════════════════════
#define UNLOCK_DURATION 5000    // 5 seconds
#define RELAY_ACTIVE_LOW true   // true if relay activates on LOW
#define SOLENOID_REVERSE false  // false = needs power to UNLOCK

// ═══════════════════════════════════════════════════════════
// BUZZER PATTERNS
// ═══════════════════════════════════════════════════════════
#define BEEP_SUCCESS_DURATION   300     // ms
#define BEEP_ERROR_DURATION     200     // ms
#define BEEP_ERROR_PAUSE        200     // ms
#define BEEP_WARNING_DURATION   150     // ms
#define BEEP_WARNING_PAUSE      150     // ms

// ═══════════════════════════════════════════════════════════
// SYSTEM TIMING
// ═══════════════════════════════════════════════════════════
#define SCREEN_TIMEOUT  15000   // 15 seconds
#define SERIAL_BAUD     115200
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

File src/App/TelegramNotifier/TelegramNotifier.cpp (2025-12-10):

// ═══════════════════════════════════════════════════════════
// FILE: src/App/TelegramNotifier/TelegramNotifier.cpp
// ═══════════════════════════════════════════════════════════
#include "TelegramNotifier.h"

TelegramNotifier::TelegramNotifier(const String& bot_token, const String& chat_id, WiFiManager* wifi_mgr)
    : botToken(bot_token), chatId(chat_id), wifi(wifi_mgr), enabled(true) {
}

void TelegramNotifier::init() {
    Serial.println("🔧 TelegramNotifier: Initializing...");
    Serial.printf("   - Bot Token: %s\n", botToken.substring(0, 10).c_str() + String("..."));
    Serial.printf("   - Chat ID: %s\n", chatId.c_str());
    Serial.println("✅ TelegramNotifier: Ready");
}

bool TelegramNotifier::sendMessage(const String& message) {
    if (!enabled) {
        Serial.println("📱 Telegram: Disabled, message not sent");
        return false;
    }
    
    if (!wifi->isConnected()) {
        Serial.println("❌ Telegram: WiFi not connected!");
        return false;
    }
    
    // URL encode message
    String encodedMsg = urlEncode(message);
    
    // Build Telegram API URL
    String url = "https://api.telegram.org/bot" + botToken +
                 "/sendMessage?chat_id=" + chatId +
                 "&text=" + encodedMsg;
    
    Serial.println("📱 Telegram: Sending message...");
    
    HTTPClient http;
    http.begin(url);
    http.setTimeout(10000); // 10 second timeout
    
    int httpCode = http.GET();
    
    if (httpCode > 0) {
        String payload = http.getString();
        Serial.printf("   - Response code: %d\n", httpCode);
        
        if (httpCode == 200) {
            Serial.println("   ✅ Message sent successfully!");
            http.end();
            return true;
        } else {
            Serial.printf("   ⚠️ HTTP error: %s\n", payload.c_str());
        }
    } else {
        Serial.printf("   ❌ Connection error: %s\n", http.errorToString(httpCode).c_str());
    }
    
    http.end();
    return false;
}

void TelegramNotifier::sendUnlockNotification(const String& method) {
    String emoji = "✅";
    String message = emoji + " Door Unlocked!\n"
                     "Method: " + method + "\n"
                     "Time: " + String(millis() / 1000) + "s";
    sendMessage(message);
}

void TelegramNotifier::sendAccessDeniedAlert(const String& reason) {
    String emoji = "⚠️";
    String message = emoji + " Access Denied!\n"
                     "Reason: " + reason + "\n"
                     "Time: " + String(millis() / 1000) + "s";
    sendMessage(message);
}

void TelegramNotifier::sendOTP(int otp) {
    String emoji = "🔐";
    String message = emoji + " Door Access OTP\n\n"
                     "Code: " + String(otp) + "\n"
                     "Valid for 60 seconds\n\n"
                     "Do not share this code!";
    sendMessage(message);
}

void TelegramNotifier::setEnabled(bool enable) {
    enabled = enable;
    Serial.printf("📱 Telegram: Notifications %s\n", enable ? "enabled" : "disabled");
}

bool TelegramNotifier::isEnabled() const {
    return enabled;
}

String TelegramNotifier::urlEncode(const String& str) {
    String encoded = "";
    char c;
    
    for (size_t i = 0; i < str.length(); i++) {
        c = str.charAt(i);
        
        if (c == ' ') {
            encoded += "%20";
        } else if (c == '\n') {
            encoded += "%0A";
        } else if (isAlphaNumeric(c) || c == '-' || c == '_' || c == '.' || c == '~') {
            encoded += c;
        } else {
            // Encode other characters
            encoded += '%';
            if (c < 0x10) encoded += '0';
            encoded += String(c, HEX);
        }
    }
    
    return encoded;
}

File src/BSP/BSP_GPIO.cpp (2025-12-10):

// ═══════════════════════════════════════════════════════════
// FILE: src/BSP/BSP_GPIO.cpp
// ═══════════════════════════════════════════════════════════
#include "BSP_GPIO.h"

// Pin definitions from Config
#define LOCK_PIN    2
#define LED_PIN     14
#define BUZZER_PIN  27

// Keypad pins
#define KEYPAD_ROW_1  33
#define KEYPAD_ROW_2  32
#define KEYPAD_ROW_3  4
#define KEYPAD_ROW_4  15

#define KEYPAD_COL_1  26
#define KEYPAD_COL_2  25
#define KEYPAD_COL_3  17
#define KEYPAD_COL_4  16

bool BSP_GPIO::initialized = false;

void BSP_GPIO::init() {
    if (initialized) {
        Serial.println("⚠️  BSP_GPIO: Already initialized");
        return;
    }
    
    Serial.println("🔧 BSP_GPIO: Initializing GPIO pins...");
    
    initOutputPins();
    initInputPins();
    
    initialized = true;
    Serial.println("✅ BSP_GPIO: Initialization complete");
    
    printConfig();
}

void BSP_GPIO::initOutputPins() {
    Serial.println("   📤 Configuring OUTPUT pins:");
    
    // Lock Control (Relay)
    pinMode(LOCK_PIN, OUTPUT);
    digitalWrite(LOCK_PIN, HIGH); // Relay active LOW, so HIGH = locked
    Serial.printf("      - LOCK:   GPIO %d (Relay)\n", LOCK_PIN);
    
    // LED Indicator
    pinMode(LED_PIN, OUTPUT);
    digitalWrite(LED_PIN, LOW); // LED off initially
    Serial.printf("      - LED:    GPIO %d\n", LED_PIN);
    
    // Buzzer
    pinMode(BUZZER_PIN, OUTPUT);
    digitalWrite(BUZZER_PIN, LOW); // Buzzer off initially
    Serial.printf("      - BUZZER: GPIO %d\n", BUZZER_PIN);
}

void BSP_GPIO::initInputPins() {
    Serial.println("   📥 Configuring INPUT pins (Keypad):");
    
    // Keypad rows (output from keypad perspective, but we scan them)
    pinMode(KEYPAD_ROW_1, INPUT);
    pinMode(KEYPAD_ROW_2, INPUT);
    pinMode(KEYPAD_ROW_3, INPUT);
    pinMode(KEYPAD_ROW_4, INPUT);
    
    Serial.printf("      - Rows: GPIO %d, %d, %d, %d\n", 
                  KEYPAD_ROW_1, KEYPAD_ROW_2, KEYPAD_ROW_3, KEYPAD_ROW_4);
    
    // Keypad columns (input from keypad perspective)
    pinMode(KEYPAD_COL_1, INPUT_PULLUP);
    pinMode(KEYPAD_COL_2, INPUT_PULLUP);
    pinMode(KEYPAD_COL_3, INPUT_PULLUP);
    pinMode(KEYPAD_COL_4, INPUT_PULLUP);
    
    Serial.printf("      - Cols: GPIO %d, %d, %d, %d\n", 
                  KEYPAD_COL_1, KEYPAD_COL_2, KEYPAD_COL_3, KEYPAD_COL_4);
}

bool BSP_GPIO::isInitialized() {
    return initialized;
}

void BSP_GPIO::printConfig() {
    Serial.println("\n╔═══════════════════════════════════════╗");
    Serial.println("║      GPIO CONFIGURATION SUMMARY       ║");
    Serial.println("╠═══════════════════════════════════════╣");
    Serial.printf("║ Lock Control:  GPIO %-2d (Relay)      ║\n", LOCK_PIN);
    Serial.printf("║ LED Indicator: GPIO %-2d               ║\n", LED_PIN);
    Serial.printf("║ Buzzer:        GPIO %-2d               ║\n", BUZZER_PIN);
    Serial.println("╠═══════════════════════════════════════╣");
    Serial.println("║ Keypad Matrix:                        ║");
    Serial.printf("║   Rows: %2d, %2d, %2d, %2d               ║\n", 
                  KEYPAD_ROW_1, KEYPAD_ROW_2, KEYPAD_ROW_3, KEYPAD_ROW_4);
    Serial.printf("║   Cols: %2d, %2d, %2d, %2d               ║\n", 
                  KEYPAD_COL_1, KEYPAD_COL_2, KEYPAD_COL_3, KEYPAD_COL_4);
    Serial.println("╚═══════════════════════════════════════╝\n");
}
